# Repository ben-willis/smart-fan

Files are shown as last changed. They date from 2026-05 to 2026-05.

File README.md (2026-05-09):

# Smart Fan Project

A WiFi-enabled smart fan controller built on ESP32-S3 with Home Assistant integration, using ESPHome for firmware management.

## Overview

This project transforms a traditional fan into a smart, connected device with the following capabilities:
- **WiFi Connectivity**: ESP32-S3 microcontroller for wireless control
- **Home Assistant Integration**: Full API integration for home automation
- **Physical Controls**: GPIO-based buttons for manual operation
- **IR Remote Support**: NEC protocol infrared remote control
- **Advanced Features**: 3-speed control, oscillation mode, preset modes (Sleep, Nature, Normal)
- **Custom PCB**: Professionally designed KiCad PCB with production-ready Gerber files

## Documentation

- [Docs Index](docs/README.md)
- [Project Story](docs/project-story.md)
- [UART Protocol](docs/uart-protocol.md)
- [Hardware Notes](docs/hardware-notes.md)

If you are new to this repository, start with [Project Story](docs/project-story.md), then use [UART Protocol](docs/uart-protocol.md) while reviewing firmware behavior.

## Hardware

### Microcontroller
- **Board**: ESP32-S3-DevKitC-1
- **Framework**: Arduino

### Physical Controls
- **On/Off Button**: GPIO11
- **Speed Control Button**: GPIO10 (cycles through 3 speeds)
- **Oscillation Toggle Button**: GPIO34
- **Mode Button**: GPIO9 (reserved for future use)
- **Timer Button**: GPIO8 (reserved for future use)

### IR Remote
- **Protocol**: NEC
- **Address**: 0xFE01
- **Supported Commands**:
  - On/Off: 0xFC03
  - Speed Cycle: 0xF807
  - Oscillation: 0xEC13

### Visual Indicators
- **Low Speed LED**: GPIO15
- **Medium Speed LED**: GPIO18
- **High Speed LED**: GPIO19
- **Normal Mode LED**: GPIO14
- **Rhythm Mode LED**: GPIO17
- **Sleep Mode LED**: GPIO20

### Communication
- **Fan UART**: GPIO43 (TX), GPIO44 (RX) @ 334 baud
- **Remote Receiver**: GPIO7 (inverted, NEC protocol via RMT channel 4)

## Features

### Fan Control
- **3-Speed Operation**: Low, Medium, High
- **Oscillation Mode**: On/Off toggle
- **Preset Modes**: 
  - Sleep mode
  - Nature mode
  - Normal mode
- **State Preservation**: Always powers off on restart

### Connectivity
- **WiFi**: Configurable SSID and password with fallback hotspot
- **API**: Home Assistant encrypted API communication
- **OTA Updates**: Over-the-air firmware updates via ESPHome

### Debugging
- **Serial Logging**: DEBUG level logging enabled
- **UART Debug**: Bidirectional UART debugging for fan communication
- **State Tracking**: Comprehensive logging of all state changes

## Project Structure

```
smart-fan/
├── README.md                  # Project documentation
├── secrets.yaml               # WiFi and API credentials (not in git)
│
├── firmware/                  # ESPHome firmware configuration
│   └── smart-fan.yml          # Main ESPHome configuration
│
├── hardware/                  # KiCad PCB design files
│   ├── smart-fan.kicad_sch    # Schematic
│   ├── smart-fan.kicad_pcb    # PCB layout
│   ├── smart-fan.kicad_pro    # Project file
│   ├── Gerber/                # Manufacturing files
│   │   ├── smart-fan-F_Cu.gbr
│   │   ├── smart-fan-B_Cu.gbr
│   │   ├── smart-fan-*.gbr    # Additional layers
│   │   ├── smart-fan-PTH.drl
│   │   └── smart-fan-NPTH.drl
│   └── production/            # Production data
│       ├── bom.csv            # Bill of materials
│       ├── designators.csv
│       ├── positions.csv      # Pick & place
│       └── netlist.ipc
│
├── docs/                      # Project docs, protocol notes, and hardware references
│
└── venv/                      # Python virtual environment
```

## Setup & Installation

### Prerequisites
- Python 3.8+
- ESPHome CLI or Web UI
- ESP32-S3-DevKitC-1 board
- USB-C cable for programming

### Configuration

1. **Create secrets.yaml** with the following variables:
   ```yaml
   api_encryption_key: "your_api_key_here"
   ota_password: "your_ota_password"
   wifi_ssid: "your_wifi_ssid"
   wifi_password: "your_wifi_password"
   ap_password: "fallback_hotspot_password"
   ```

2. **Create a virtual environment and install dependencies**:
   ```bash
   python -m venv venv
   source venv/Scripts/activate
   python -m pip install -r requirements.txt
   ```

3. **Build and Upload Firmware**:
   ```bash
   esphome run firmware/smart-fan.yml
   ```

4. **First Flash**:
   - Connect ESP32-S3 via USB-C
   - Select the COM port
   - Let ESPHome handle the flashing process

### WiFi & API Setup

- **Normal Operation**: Connects to specified WiFi SSID
- **Fallback Mode**: If WiFi connection fails, opens "Smart Fan Fallback Hotspot"
- **API Encryption**: Uses Home Assistant encrypted API for secure communication
- **OTA Updates**: After initial flash, updates can be done wirelessly

## Home Assistant Integration

Once configured, the Smart Fan will appear in Home Assistant with:
- **Fan entity**: Full control (on/off, speed, oscillation)
- **Preset modes**: Select Sleep, Nature, or Normal modes
- **Binary sensors**: Button press detection
- **Switches**: Individual control for lights and modes

Add to Home Assistant `configuration.yaml`:
```yaml
esphome:
  - firmware/smart-fan.yml
```

## Development

### Building PCB
- KiCad 8.0+ compatible
- Design files in `hardware/`
- Gerber files ready for ordering from fabricators
- Production data includes BOM, designators, and pick & place positions

### Serial Communication
The fan communicates via UART at 334 baud. Commands are 5-byte packets with checksums:
- Format: `[0x5a, SPEED_BITS, MODE_BITS, OSCILLATION_BITS, CHECKSUM]`
- See `docs/uart-protocol.md` for protocol details

### OTA Updates
After initial programming, update firmware wirelessly:
```bash
esphome run firmware/smart-fan.yml
```

## Debugging

### View Logs
```bash
esphome logs firmware/smart-fan.yml
```

### Monitor UART Communication
UART debugging is enabled with bidirectional logging. Connect to the serial monitor to see raw commands sent to the fan:
```bash
esphome logs firmware/smart-fan.yml
```

## Future Enhancements

- Mode button functionality for additional control modes
- Timer button integration for scheduled operation
- Display integration for status information
- Additional preset modes and customization
- Mobile app control via Home Assistant

## License

[Specify your license here]

## References

- [ESPHome Documentation](https://esphome.io/)
- [Home Assistant](https://www.home-assistant.io/)
- [ESP32-S3 DevKitC-1](https://docs.espressif.com/projects/esp-idf/en/latest/esp32s3/hw-reference/esp32s3/user-guide-devkitc-1.html)
- [KiCad Documentation](https://docs.kicad.org/)

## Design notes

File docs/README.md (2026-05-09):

# Documentation

This folder contains project documentation for the Smart Fan reverse-engineering and custom controller build.

## Start Here

- If you want the story and context, read [Project Story](project-story.md)
- If you want protocol details, read [UART Protocol](uart-protocol.md)
- If you want hardware layout and assets, read [Hardware Notes](hardware-notes.md)

## Contents

- [Project Story](project-story.md): End-to-end log from teardown to ESPHome integration
- [UART Protocol](uart-protocol.md): Reverse-engineered fan serial protocol and command map
- [Hardware Notes](hardware-notes.md): Board-level findings, connector mapping, and design decisions
- [Schematic PDF](schematic.pdf): Printable schematic export
- [Schematic Image](schematic.png): Quick schematic preview
- [Front Render](front.png): Custom PCB front render
- [Back Render](back.png): Custom PCB back render
- [3D Render](3d.png): Custom PCB 3D view
- [Fan Model](fan-model.png): John Lewis FZ10 17KR fan
- [Fan In Situ](fan-in-situ.jpg): Original installation
- [Control Board Top](control-board-top.jpg): Stock board teardown
- [Control Board Bottom](control-board-bottom.jpg): Stock board connector side

## Scope

These docs focus on:
- Reverse-engineering the fan communication path
- Integrating ESPHome with Home Assistant
- Replacing the stock display/input board with a custom PCB

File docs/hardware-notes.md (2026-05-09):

# Hardware Notes

## Safety

This project interfaces with a mains-powered appliance. Only work on disconnected hardware, and follow appropriate electrical safety practices.

## Original Fan Boards

The stock fan electronics use two PCBs:
- Main board for power/motor control
- Front-panel board for buttons, LEDs, and IR receiver

Inter-board connector signals:
- TX
- RX
- VDD (about 5V)
- GND

## Reverse-Engineering Findings

- The main board accepts UART control commands at 334 baud.
- State appears to be continuously transmitted by the stock controller.
- Full bidirectional, high-level synchronization with the original display board was not confirmed.

## Custom Board Direction

The custom board replaces front-panel logic while preserving user experience:
- Physical buttons for on/off, speed, timer, and mode positions
- LED indicators for speed and modes
- IR receiver input
- ESP32 integration for Home Assistant control

## Current Assets in Repo

- KiCad source files in `hardware/`
- Manufacturing Gerbers in `hardware/Gerber/`
- Production files (BOM, designators, positions, netlist) in `hardware/production/`
- Visual references in this `docs/` folder

## Design Intent

The custom board aims to preserve the original user experience while moving logic to ESPHome:
- Keep physical buttons and status LEDs
- Keep IR receiver support
- Keep compatibility with original fan UART control path

## Visual References

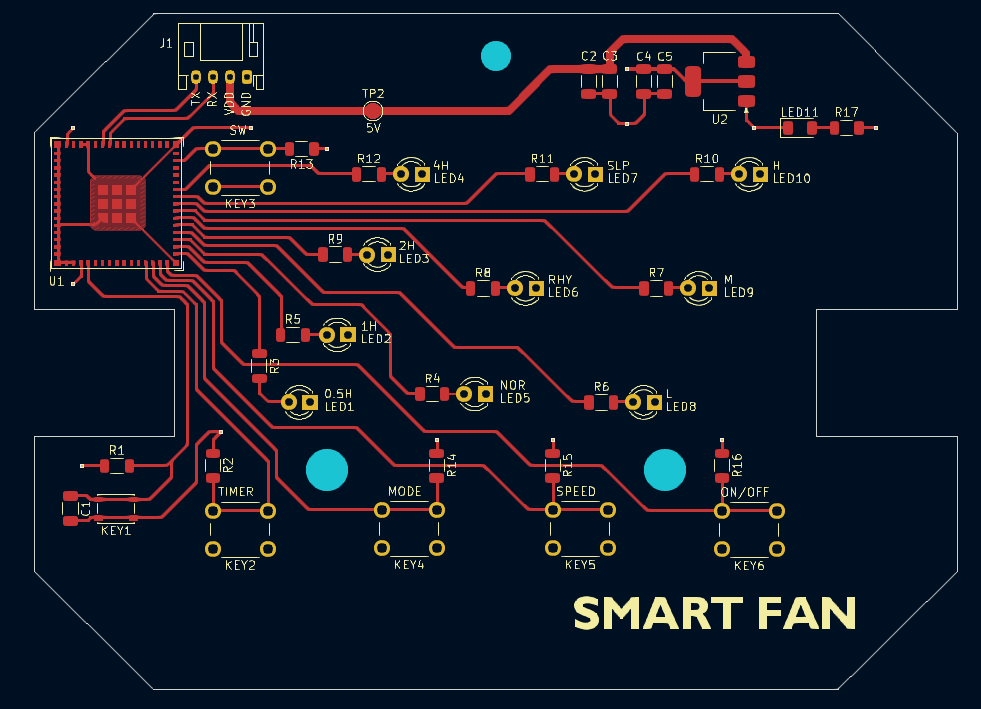
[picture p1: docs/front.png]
Front render


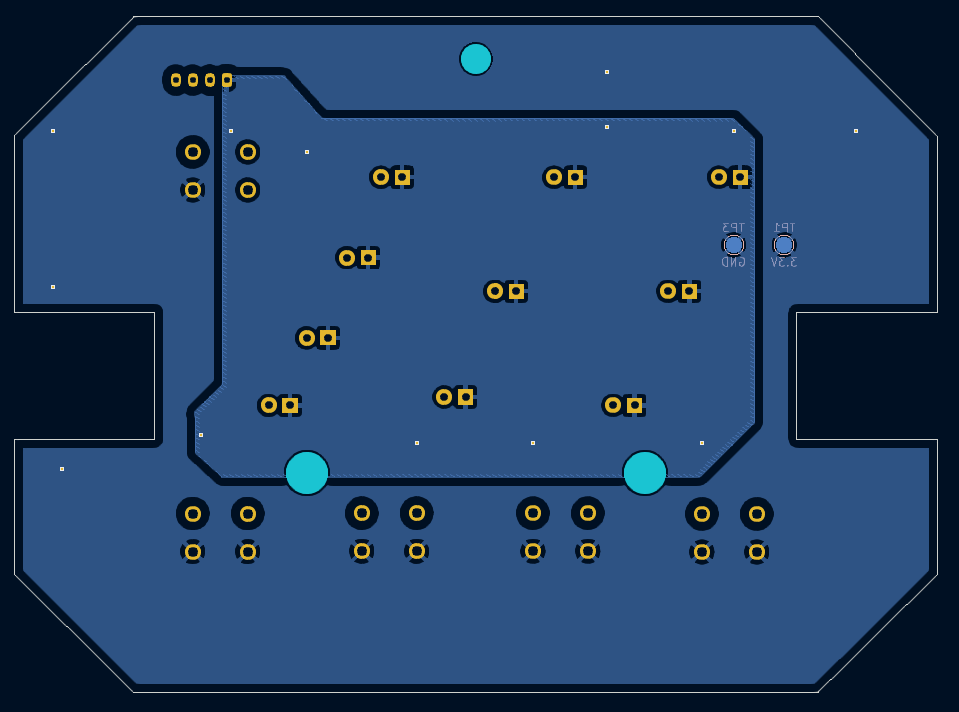
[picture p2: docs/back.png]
Back render


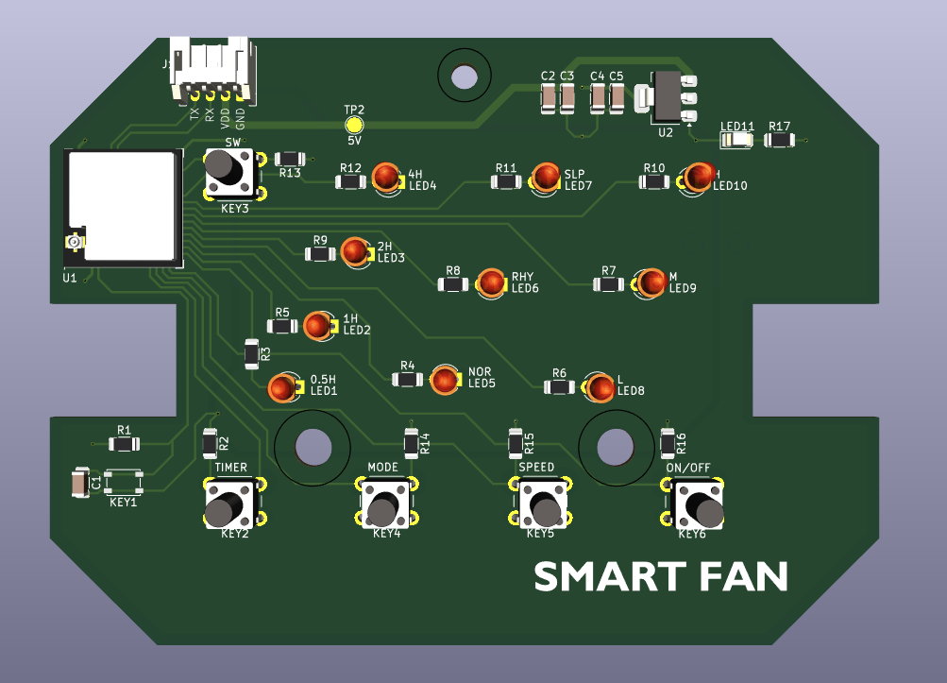
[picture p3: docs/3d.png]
3D render


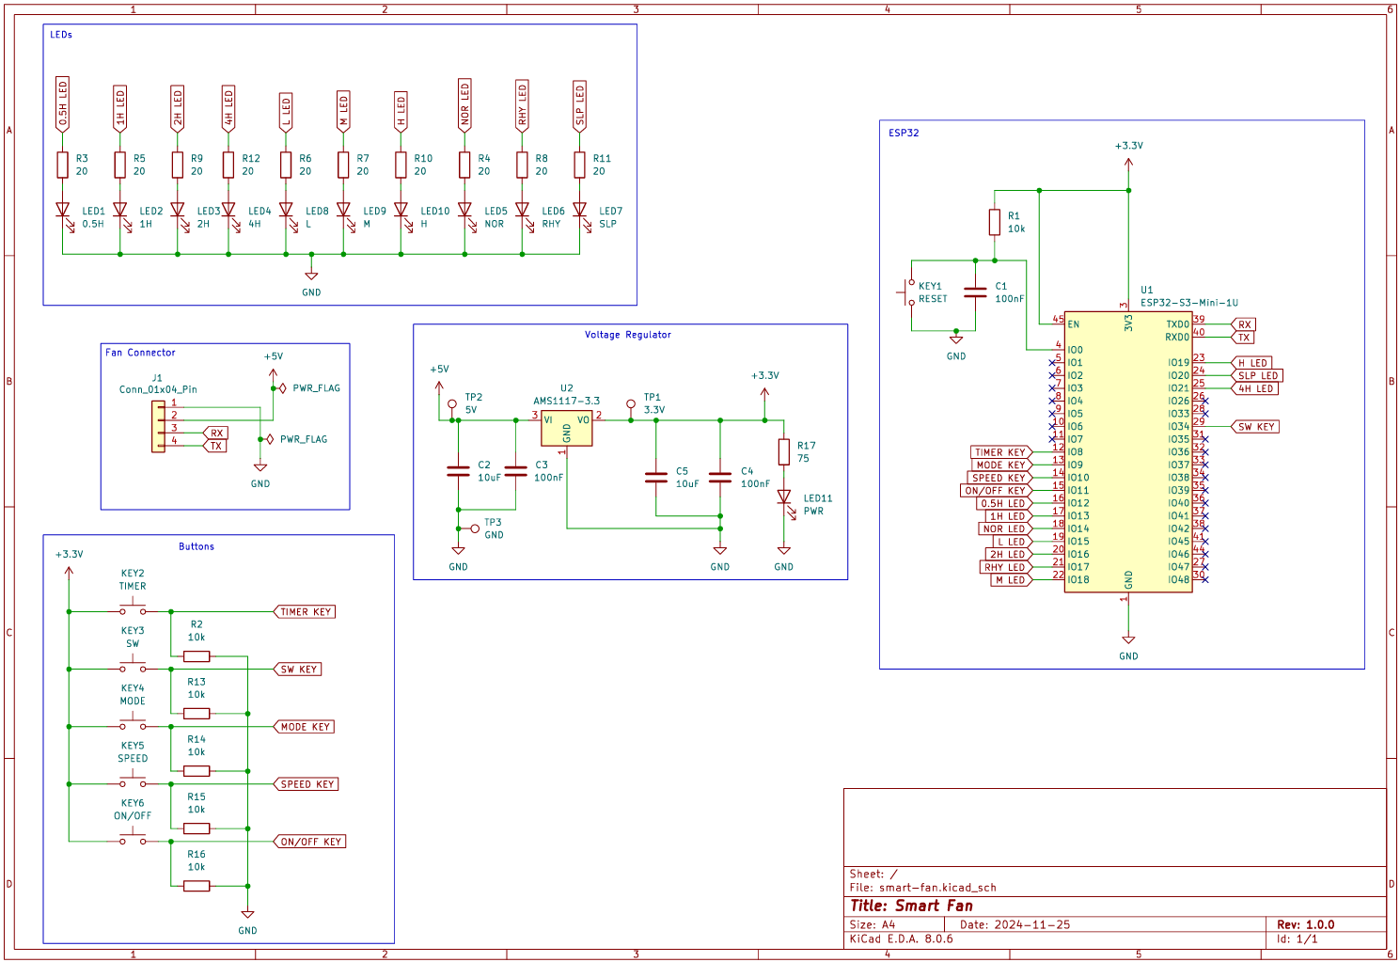
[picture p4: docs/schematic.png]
Schematic preview


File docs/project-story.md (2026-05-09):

# Smart Fan Project Story

## Goal

Control a John Lewis FZ10 17KR fan from Home Assistant using ESPHome and a custom ESP32-based front panel board.

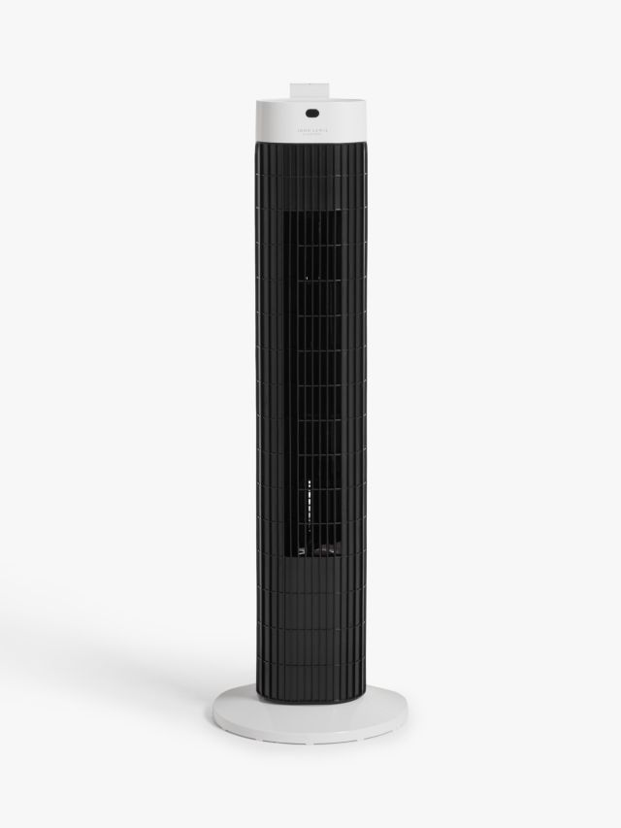
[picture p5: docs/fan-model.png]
FZ10 17KR Fan


## Background

The fan has two internal boards:
- Main control board connected to motor and power path
- Display/input board connected to LEDs, buttons, and IR receiver

The boards communicate over a 4-wire link:
- TX
- RX
- VDD (about 5V)
- GND

### Teardown Photos

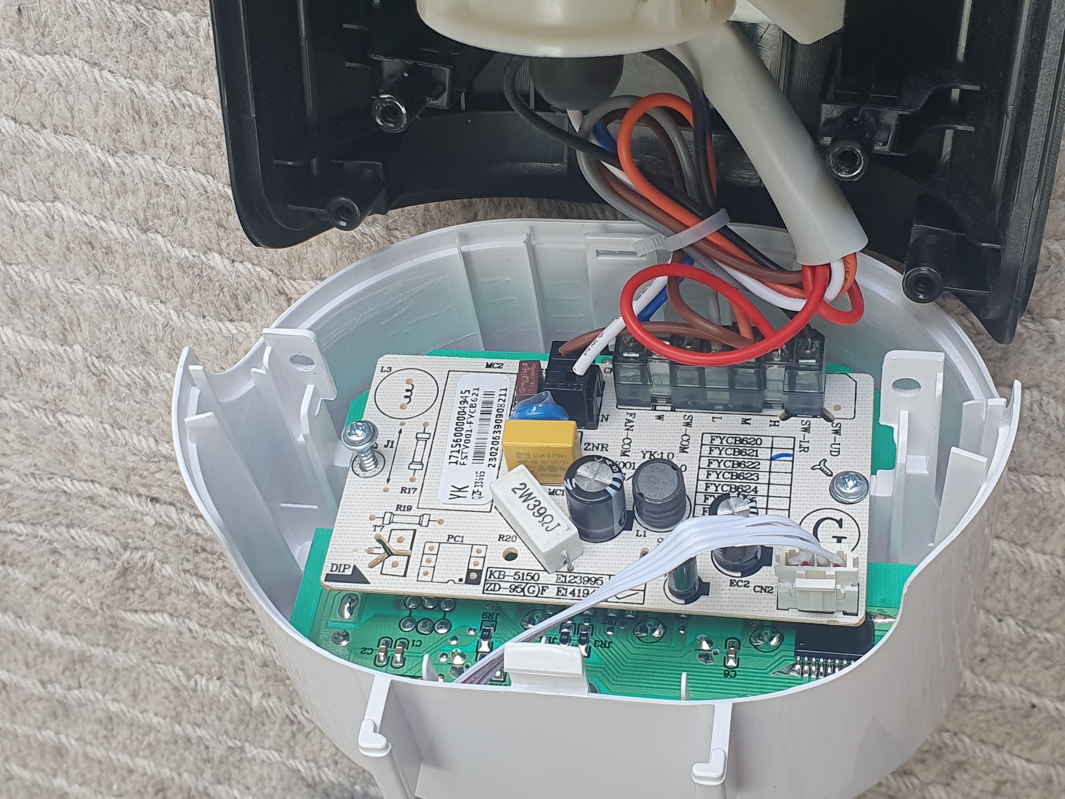
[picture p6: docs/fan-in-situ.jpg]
Fan in situ

*Original fan installed*

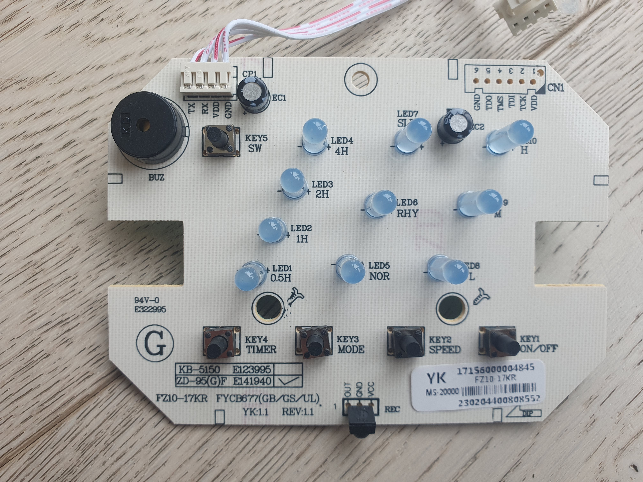
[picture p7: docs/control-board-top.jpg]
Control board - top side

*Top control/display board with buttons, LEDs, and IR receiver*

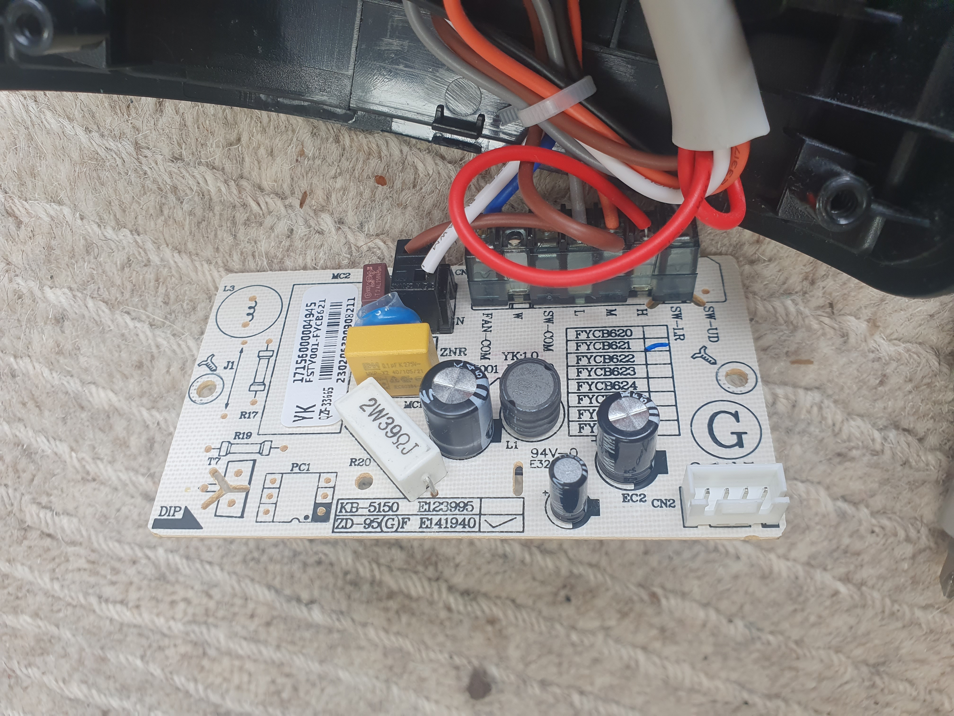
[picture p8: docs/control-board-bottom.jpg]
Control board - bottom side

*Bottom side showing power path and connector*

## Reverse Engineering

The original control path was inspected by probing RX/TX with an Arduino.

Observed behavior:
- TX line from the fan side appears mostly high
- RX line carries a repeating 5-byte message representing current fan state
- Effective baud rate is 334

This gave enough information to emulate commands from ESPHome.

## ESPHome Integration

Implemented in firmware:
- Fan on/off
- 3 speeds (low, medium, high)
- Oscillation toggle
- Home Assistant API + OTA updates

Current status:
- Core fan functions are stable from Home Assistant
- Mode and timer button behavior are still open for future firmware work

## Why a Custom PCB

The original display board appears to be mostly write-only from the mainboard protocol perspective, making state synchronization difficult.

A custom board was designed to:
- Keep local physical controls
- Keep LED indicators
- Keep IR receiver support
- Provide reliable ESP32 integration with known GPIO mapping

## Milestones

Completed:
- LED resistor validation
- Button pull-up/pull-down validation
- Connector footprint identification
- PCB review and fabrication export

Open:
- UART-only programming workflow validation for ESP32 on final hardware

## Current Outcome

The project now has:
- Working Home Assistant fan control over UART
- A custom KiCad PCB design with manufacturing outputs in the repository
- A documented protocol baseline for future extension (timer/modes)

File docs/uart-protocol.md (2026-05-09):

# Fan UART Protocol

This document captures the reverse-engineered fan control protocol used by the original board.

## Serial Settings

- Baud rate: 334
- Payload: 5 bytes
- Byte order: fixed-length frame

## State Mapping

The frame encodes fan state as power, speed, and oscillation fields. The stock controller repeats frames continuously for the current state.

## Frame Format

`[START, POWER, SPEED, OSC, CHECKSUM]`

- START: expected `0x5A`
- POWER: power state bitfield
- SPEED: speed bitfield
- OSC: oscillation bitfield
- CHECKSUM: frame checksum used by the fan controller

## Known Command Frames

### Power Off

`{ 0x5A, 0x40, 0x80, 0x20, 0x9F }`

### Power On, Oscillation Off

- Low: `{ 0x5A, 0xC0, 0x80, 0x20, 0x1F }`
- Medium: `{ 0x5A, 0xC0, 0x40, 0x20, 0xEF }`
- High: `{ 0x5A, 0xC0, 0xC0, 0x20, 0x6F }`

### Power On, Oscillation On

- Low: `{ 0x5A, 0xC0, 0x80, 0xA0, 0xEF }`
- Medium: `{ 0x5A, 0xC0, 0x40, 0xA0, 0x6F }`
- High: `{ 0x5A, 0xC0, 0xC0, 0xA0, 0xAF }`

## Implementation Notes

- The original board repeats state frames continuously.
- Current implementation is command-driven from ESPHome fan state callbacks.
- If new modes are discovered, add them here first and then mirror in firmware.

## Open Questions

- Whether the stock display/input board supports a reliable readback channel
- Whether additional mode/timer commands exist beyond the currently mapped set

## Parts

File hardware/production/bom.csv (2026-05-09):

Designator | Footprint | Quantity | Value | LCSC Part #
C2 | 1206 | 1 | 1uF | C1848
C3 | 1206 | 1 | 4.7uF | C51205
C4 | 1206 | 1 | 1uF | C1848
J1 | JST_XH_S4B-XH-A_1x04_P2.50mm_Horizontal | 1 | Conn_01x04_Pin | C157925
J3 | PinHeader_1x02_P2.54mm_Horizontal | 1 | Conn_01x02 | C492410
KEY2 | SW_PUSH_6mm_H9.5mm | 1 | TIMER | C455119
KEY3 | SW_PUSH_6mm_H9.5mm | 1 | SW | C455119
KEY4 | SW_PUSH_6mm_H9.5mm | 1 | MODE | C455119
KEY5 | SW_PUSH_6mm_H9.5mm | 1 | SPEED | C455119
KEY6 | SW_PUSH_6mm_H9.5mm | 1 | ON/OFF | C455119
LED1 | LED_D3.0mm | 1 | Blue | C330760
LED10 | LED_D3.0mm | 1 | Blue | C330760
LED2 | LED_D3.0mm | 1 | Blue | C330760
LED3 | LED_D3.0mm | 1 | Blue | C330760
LED4 | LED_D3.0mm | 1 | Blue | C330760
LED5 | LED_D3.0mm | 1 | Blue | C330760
LED6 | LED_D3.0mm | 1 | Blue | C330760
LED7 | LED_D3.0mm | 1 | Blue | C330760
LED8 | LED_D3.0mm | 1 | Blue | C330760
LED9 | LED_D3.0mm | 1 | Blue | C330760
R1 | 1206 | 1 | 10k | C17902
R10, R11, R12, R3, R4, R5, R6, R7, R8, R9 | 1206 | 10 | 100 | C17901
TP1 | TestPoint_Pad_D2.0mm | 1 | 3.3V
TP2 | TestPoint_Pad_D2.0mm | 1 | 5V
TP3 | TestPoint_Pad_D2.0mm | 1 | GND
U1 | ESP32-S2-MINI-1U | 1 | ESP32-S3-Mini-1U | C2980299
U2 | SOT-223-3_TabPin2 | 1 | AP7361C-33E | C500795
U3 | Vishay_MINICAST-3Pin | 1 | TSOP382xx | C141632

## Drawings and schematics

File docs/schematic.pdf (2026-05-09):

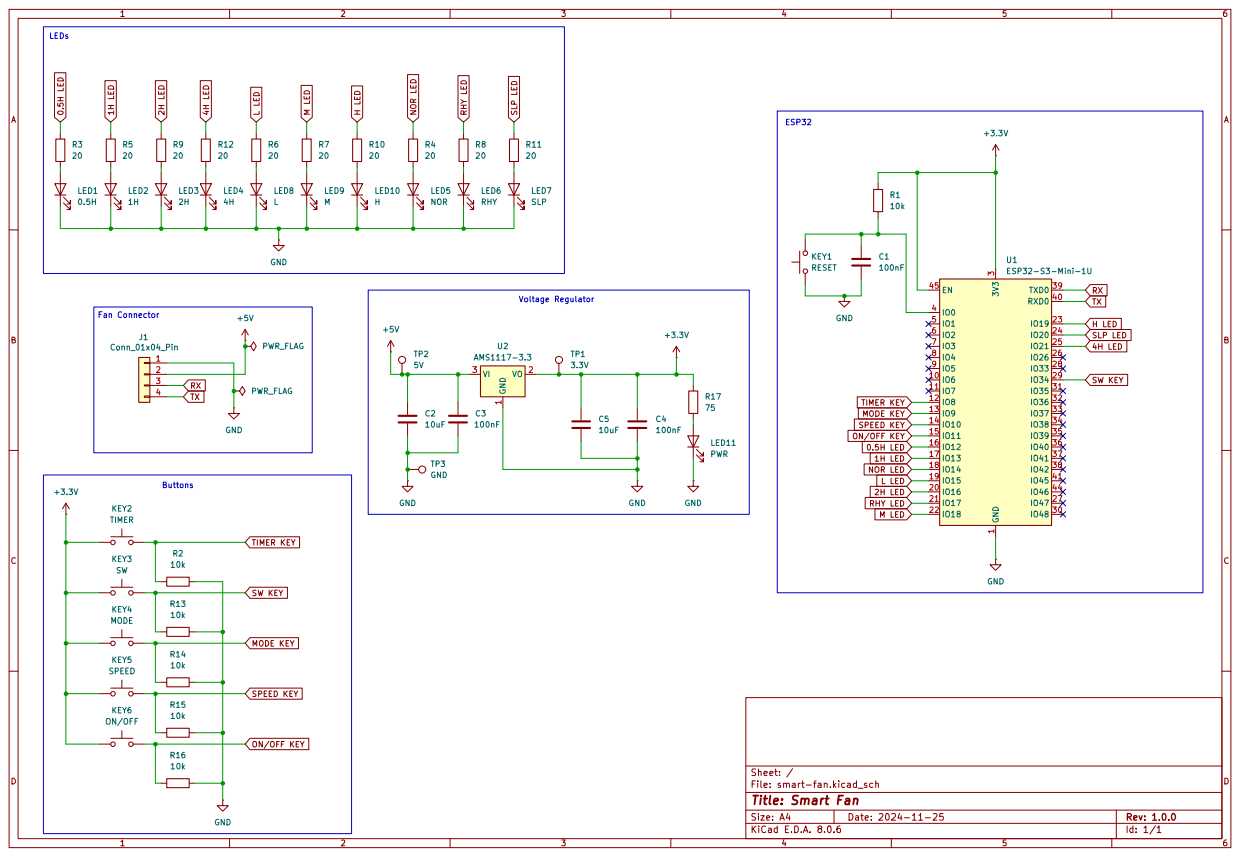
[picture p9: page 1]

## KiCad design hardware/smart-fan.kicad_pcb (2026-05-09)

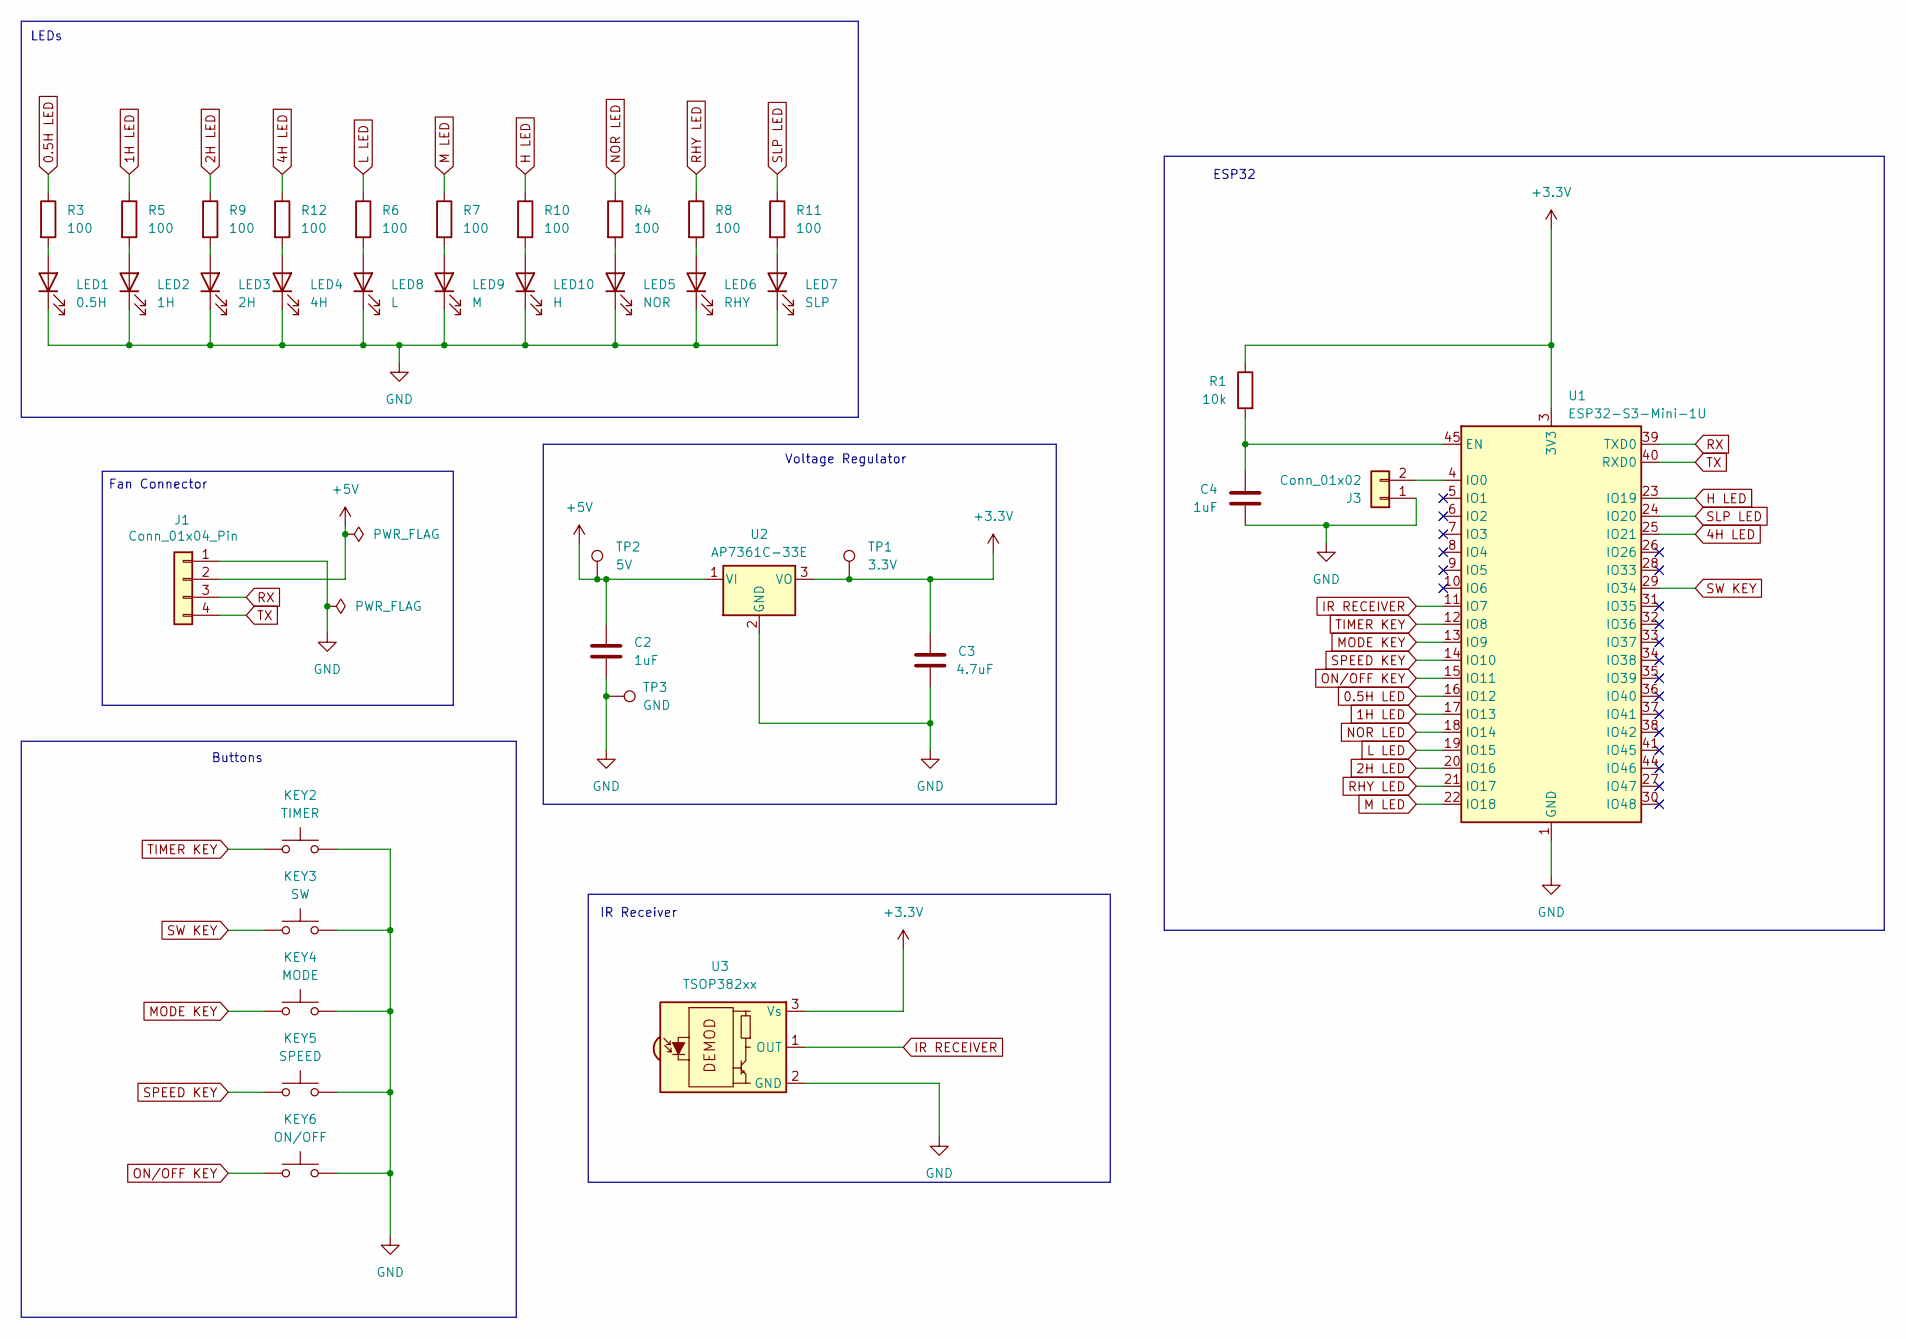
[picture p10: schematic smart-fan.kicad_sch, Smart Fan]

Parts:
C2: 1uF; C_1206_3216Metric; LCSC Part # C13585
C3: 4.7uF; C_1206_3216Metric; LCSC Part # C24497
C4: 1uF; C_1206_3216Metric; LCSC Part # C24497
J1: Conn_01x04_Pin; JST_XH_S4B-XH-A_1x04_P2.50mm_Horizontal; LCSC Part # C2286
J3: Conn_01x02; PinHeader_1x02_P2.54mm_Horizontal
KEY2: TIMER; SW_PUSH_6mm_H9.5mm; LCSC Part # C2837519
KEY3: SW; SW_PUSH_6mm_H9.5mm; LCSC Part # C2837519
KEY4: MODE; SW_PUSH_6mm_H9.5mm; LCSC Part # C2837519
KEY5: SPEED; SW_PUSH_6mm_H9.5mm; LCSC Part # C2837519
KEY6: ON/OFF; SW_PUSH_6mm_H9.5mm; LCSC Part # C2837519
LED1: 0.5H; LED_D3.0mm; LCSC Part # C330760
LED2: 1H; LED_D3.0mm; LCSC Part # C330760
LED3: 2H; LED_D3.0mm; LCSC Part # C330760
LED4: 4H; LED_D3.0mm; LCSC Part # C330760
LED5: NOR; LED_D3.0mm; LCSC Part # C330760
LED6: RHY; LED_D3.0mm; LCSC Part # C330760
LED7: SLP; LED_D3.0mm; LCSC Part # C330760
LED8: L; LED_D3.0mm; LCSC Part # C330760
LED9: M; LED_D3.0mm; LCSC Part # C330760
LED10: H; LED_D3.0mm; LCSC Part # C330760
R1: 10k; R_1206_3216Metric; LCSC Part # C25804
R3, R4, R5, R6, R7, R8, R9, R10, R11, R12: 100; R_1206_3216Metric; LCSC Part # C22859
TP1: 3.3V; TestPoint_Pad_D2.0mm
TP2: 5V; TestPoint_Pad_D2.0mm
TP3: GND; TestPoint_Pad_D2.0mm
U1: ESP32-S3-Mini-1U; ESP32-S2-MINI-1U; LCSC Part # C2980299
U2: AP7361C-33E; SOT-223-3_TabPin2; LCSC Part # C5250992
U3: TSOP382xx; Vishay_MINICAST-3Pin

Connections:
0.5H LED: R3.1, U1.16 (IO12)
1H LED: R5.1, U1.17 (IO13)
2H LED: R9.1, U1.20 (IO16)
4H LED: R12.1, U1.25 (IO21)
+3.3V: C3.1, R1.1, TP1.1, U1.3 (3V3), U2.3 (VO), U3.3 (Vs)
+5V: C2.1, J1.2, TP2.1, U2.1 (VI)
GND: C2.2, C3.2, C4.2, J1.1, J3.1, KEY2.2, KEY3.2, KEY4.2, KEY5.2, KEY6.2, LED1.1 (K), LED2.1 (K), LED3.1 (K), LED4.1 (K), LED5.1 (K), LED6.1 (K), LED7.1 (K), LED8.1 (K), LED9.1 (K), LED10.1 (K), TP3.1, U1.1 (GND), U1.2 (GND), U1.42 (GND), U1.43 (GND), U1.46 (GND), U1.47 (GND), U1.48 (GND), U1.49 (GND), U1.50 (GND), U1.51 (GND), U1.52 (GND), U1.53 (GND), U1.54 (GND), U1.55 (GND), U1.56 (GND), U1.57 (GND), U1.58 (GND), U1.59 (GND), U1.60 (GND), U1.61 (GND), U1.62 (GND), U1.63 (GND), U1.64 (GND), U1.65 (GND), U2.2 (GND), U3.2 (GND)
H LED: R10.1, U1.23 (IO19)
IR RECEIVER: U1.11 (IO7), U3.1 (OUT)
L LED: R6.1, U1.19 (IO15)
M LED: R7.1, U1.22 (IO18)
MODE KEY: KEY4.1, U1.13 (IO9)
NOR LED: R4.1, U1.18 (IO14)
unnamed: J3.2, U1.4 (IO0)
unnamed: LED1.2 (A), R3.2
unnamed: LED2.2 (A), R5.2
unnamed: LED3.2 (A), R9.2
unnamed: LED4.2 (A), R12.2
unnamed: LED5.2 (A), R4.2
unnamed: LED6.2 (A), R8.2
unnamed: LED7.2 (A), R11.2
unnamed: LED8.2 (A), R6.2
unnamed: LED9.2 (A), R7.2
unnamed: LED10.2 (A), R10.2
unnamed: C4.1, R1.2, U1.45 (EN)
ON/OFF KEY: KEY6.1, U1.15 (IO11)
RHY LED: R8.1, U1.21 (IO17)
RX: J1.3, U1.39 (TXD0)
SLP LED: R11.1, U1.24 (IO20)
SPEED KEY: KEY5.1, U1.14 (IO10)
SW KEY: KEY3.1, U1.29 (IO34)
TIMER KEY: KEY2.1, U1.12 (IO8)
TX: J1.4, U1.40 (RXD0)

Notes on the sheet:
Fan Connector
Buttons
IR Receiver
LEDs
ESP32
Voltage Regulator

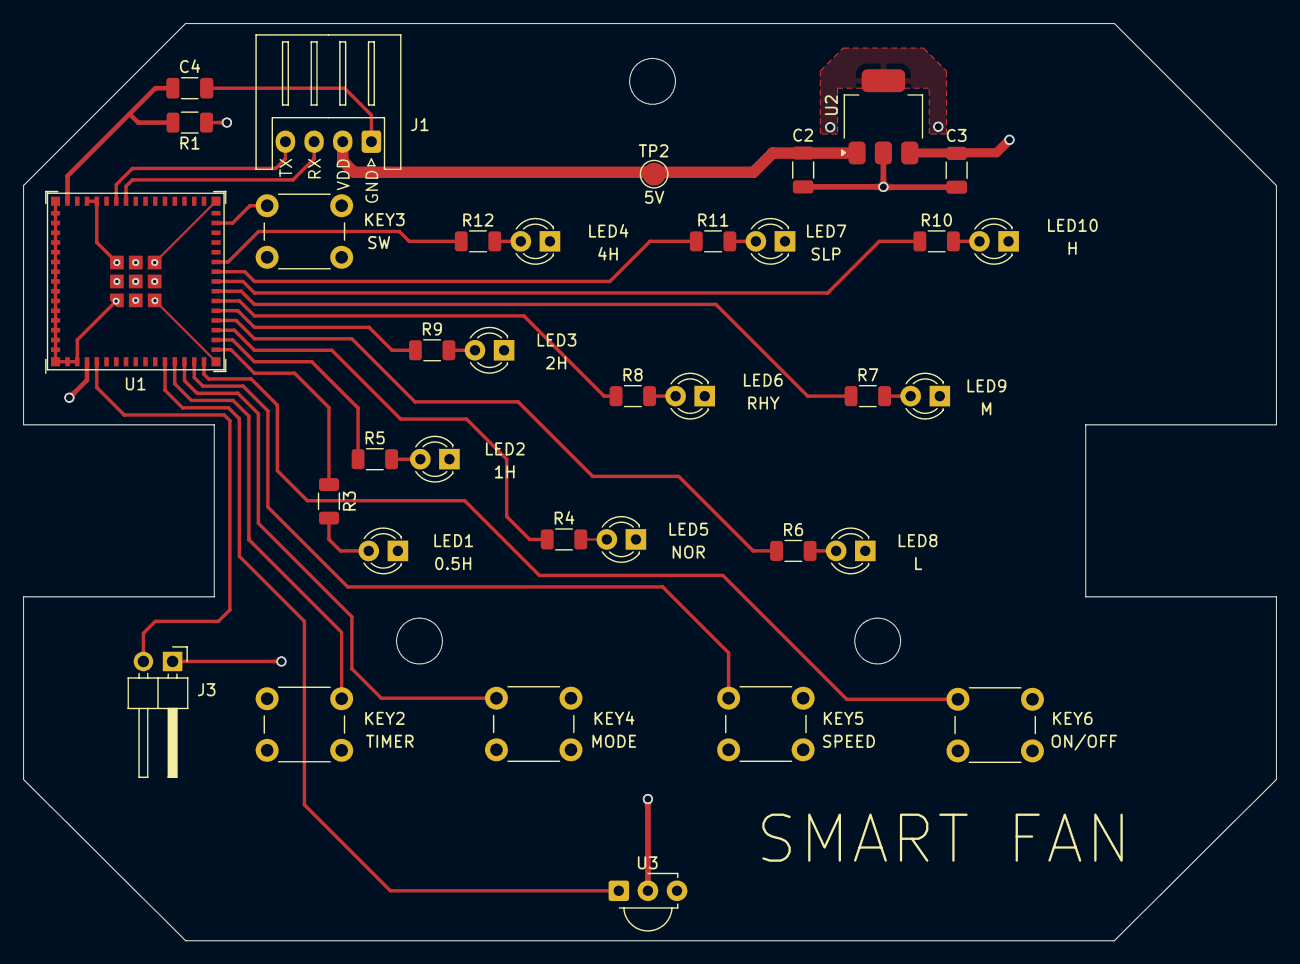
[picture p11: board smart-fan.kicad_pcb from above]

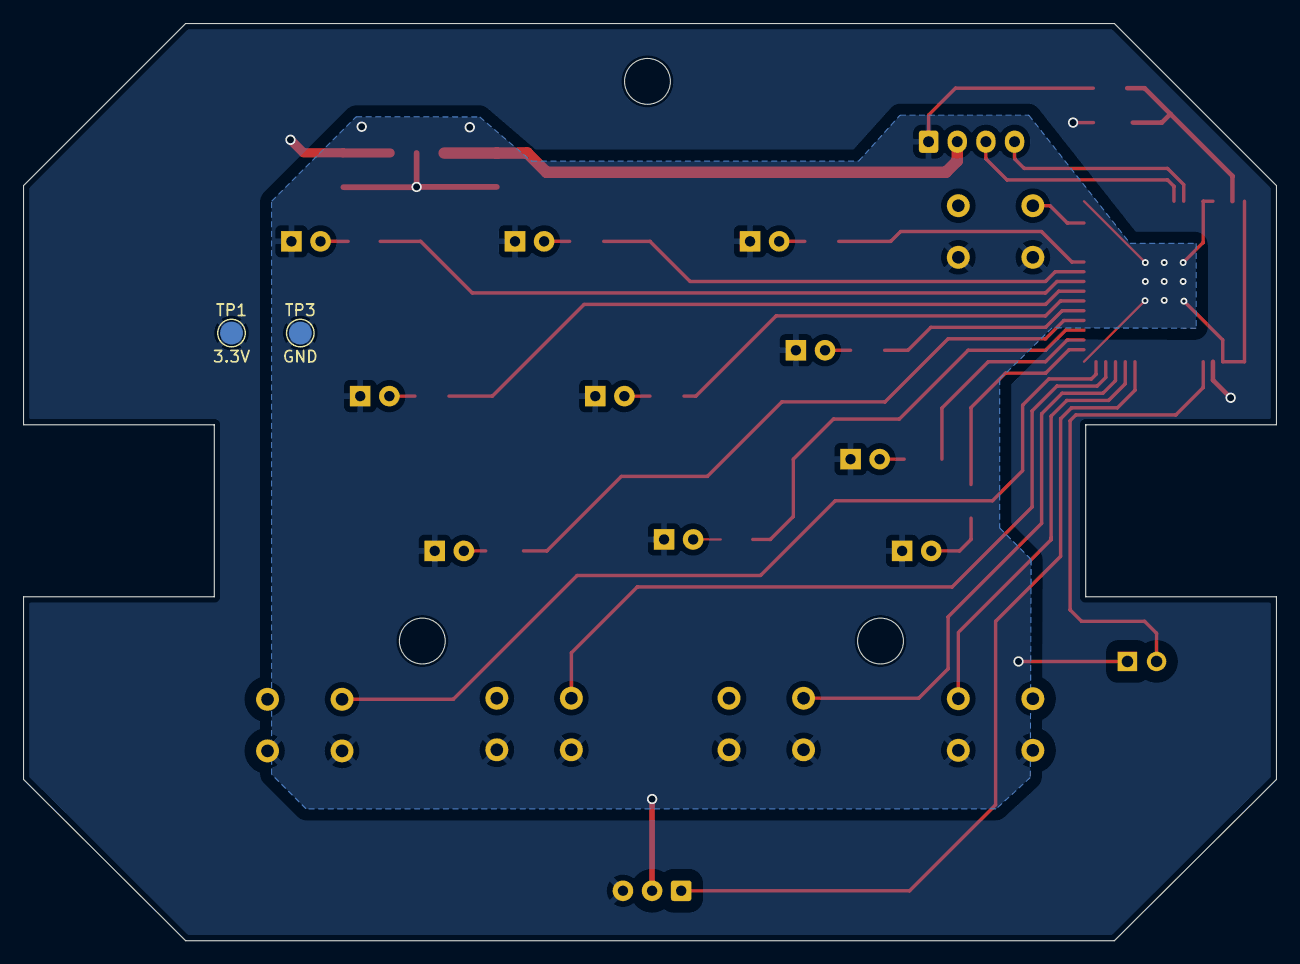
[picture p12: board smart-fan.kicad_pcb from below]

Board: 2 copper layers, 109.3 x 80.0 mm, 37 parts (2 on the bottom side), 33 nets.

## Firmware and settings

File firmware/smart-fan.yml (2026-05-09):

esphome:
  name: smart-fan
  friendly_name: Smart Fan

esp32:
  board: esp32-s3-devkitc-1
  framework:
    type: arduino

# Enable logging
logger:
  level: DEBUG

# Enable Home Assistant API
api:
  encryption:
    key: !secret api_encryption_key

ota:
  - platform: esphome
    password: !secret ota_password

wifi:
  output_power: 8.5dB
  ssid: !secret wifi_ssid
  password: !secret wifi_password
  power_save_mode: NONE

  # Enable fallback hotspot (captive portal) in case wifi connection fails
  ap:
    ssid: "Smart Fan Fallback Hotspot"
    password: !secret ap_password

captive_portal:

globals:
  - id: timer_remaining_seconds
    type: int
    restore_value: false
    initial_value: "0"

script:
  - id: toggle_oscilating
    mode: queued
    then:
      - lambda: >-
          auto oscilating = id(smart_fan).oscillating;
          auto call = id(smart_fan).make_call();
          call.set_oscillating(!oscilating);
          call.perform();

  - id: update_timer_indicators
    mode: single
    then:
      - lambda: |-
          int display_minutes = 0;
          if (id(timer_remaining_seconds) > 0) {
            display_minutes = ((id(timer_remaining_seconds) + 1799) / 1800) * 30;
          }

          id(timer_duration_number).publish_state(display_minutes);

      - if:
          condition:
            lambda: return id(timer_remaining_seconds) > 0 && (((id(timer_remaining_seconds) + 1799) / 1800) & 0x1);
          then:
            - output.turn_on: timer_0_5h_indicator
          else:
            - output.turn_off: timer_0_5h_indicator

      - if:
          condition:
            lambda: return id(timer_remaining_seconds) > 0 && (((id(timer_remaining_seconds) + 1799) / 1800) & 0x2);
          then:
            - output.turn_on: timer_1h_indicator
          else:
            - output.turn_off: timer_1h_indicator

      - if:
          condition:
            lambda: return id(timer_remaining_seconds) > 0 && (((id(timer_remaining_seconds) + 1799) / 1800) & 0x4);
          then:
            - output.turn_on: timer_2h_indicator
          else:
            - output.turn_off: timer_2h_indicator

      - if:
          condition:
            lambda: return id(timer_remaining_seconds) > 0 && (((id(timer_remaining_seconds) + 1799) / 1800) & 0x8);
          then:
            - output.turn_on: timer_4h_indicator
          else:
            - output.turn_off: timer_4h_indicator

  - id: cancel_timer
    mode: single
    then:
      - globals.set:
          id: timer_remaining_seconds
          value: "0"
      - script.execute: update_timer_indicators

  - id: apply_timer_duration
    mode: single
    parameters:
      minutes: int
    then:
      - lambda: |-
          if (minutes <= 0) {
            id(cancel_timer)->execute();
            return;
          }

          if (!id(smart_fan).state) {
            id(cancel_timer)->execute();
            return;
          }

          id(timer_remaining_seconds) = minutes * 60;
          id(update_timer_indicators)->execute();

  - id: timer_button_cycle
    mode: single
    then:
      - lambda: |-
          int current = 0;
          if (id(timer_remaining_seconds) > 0) {
            current = ((id(timer_remaining_seconds) + 1799) / 1800) * 30;
          }

          int next = 30;

          if (current >= 450) {
            next = 0;
          } else if (current > 0) {
            next = current + 30;
          }

          id(apply_timer_duration)->execute(next);
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

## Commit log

2026-05-09 Initial commit: Smart Fan ESP32 controller with ESPHome integration
    - Complete ESPHome firmware configuration with Home Assistant API
    - Custom KiCad PCB design with manufacturing outputs (Gerbers, BOM, positions, netlist)
    - Reverse-engineered UART protocol for fan control (334 baud, 5-byte frames)
    - Comprehensive project documentation covering teardown, protocol, and hardware design
    - GPIO mapping for buttons, LEDs, IR receiver, and fan UART communication
    - Production-ready files for PCB fabrication
    [bom.csv, designators.csv, positions.csv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]
2026-05-09 Add local timer control flow and HA timer sync
